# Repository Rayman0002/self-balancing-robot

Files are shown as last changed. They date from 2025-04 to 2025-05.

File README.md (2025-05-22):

# 🤖 Self-Balancing Robot - StabilOHM

## Inhaltsverzeichnis
- [Projektbeschreibung](#projektbeschreibung)
- [Bilder und Videos](#bilder-und-videos)
- [Komponenten](#komponenten)
- [Schaltskizze](#schaltskizze)
- [Libraries](#libraries)
- [Durchgeführte Arbeiten](#durchgeführte-arbeiten)
- [Herausforderungen und Probleme](#herausforderungen-und-probleme)
- [Mögliche Erweiterungen](#mögliche-erweiterungen)
- [Fazit](#fazit)

---

## Projektbeschreibung  

Das Ziel dieses Projekts war es, einen selbstbalancierenden zweirädrigen Roboter als Differentialantrieb zu entwerfen, zu fertigen und zu programmieren. Dabei handelt es sich um ein mechatronisches System, das aufrecht bleibt, indem es kontinuierlich den Neigungswinkel misst und entsprechend gegensteuert – vergleichbar mit einem inversen Pendel.

### Motivation
Selbstbalancierende Roboter sind ein beliebtes Thema in der Robotik, da sie komplexe Regelungstechnik mit Sensorik, Echtzeitverarbeitung und Aktorik verbinden. Dieses Projekt diente dem praktischen Verständnis dieser Disziplinen und der Integration moderner Komponenten wie ODrive-Motorsteuerungen, MPU6050-Sensorik und Echtzeitregelung mit einem Teensy 4.0 Microcontroller.

### Anforderungen
- Modularer Aufbau um Erweiterungen leicht zu ermöglichen
- 10 kg Tragfähigkeit
- 2 m/s Geschwindigkeit
- Höhe ca. 75 cm (Tischhöhe)
- mindestens 2 Stunden Betriebszeit
- Ansteuerbarkeit über ROS2
- Budget von 1000 €
- Veröffentlichung und Dokumentation via Github

Folgende Bauteile wurden hierfür gestellt:
- Zwei Servomotoren, gesteuert über je ein ODrive S1 Board
- Zwei Bleisäureakkumulatoren

### Technische Umsetzung
Um die gegebenen Anforderungen zu erfüllen wurden [folgende Bauteile](https://github.com/Rayman0002/self-balancing-robot/tree/01634058a8744456b4b8e9eb85bf182ba5505895/Bestellliste) zugekauft:
- Eine MPU6050 (IMU) zur Winkelmessung, welche über I2C ausgelesen wird
- Ein Teensy 4.0 (TCU) als Hauptcontroller für das Regelungssystem (PID) der Traktion
- Ein Raspberry Pi 5 (VCU) für höhere Funktionen wie Netzwerkzugang oder ROS2-Integration
- DC/DC Wandler
- Not-Aus-Schalter

Das Chassis wurde aus Aluminiumprofilen gefertigt, um Robustheit und Modularität zu gewährleisten. Zusätzlich wurden alle spezifischen Halterungen und Aufnahmen im 3D-Druckverfahren gefertigt.

### Steuerung und Regelung
Ein geschlossener Regelkreis sorgt dafür, dass der Roboter sein Gleichgewicht selbstständig hält: Die IMU MPU6050 misst fortlaufend den aktuellen Neigungswinkel (Ist-Wert) und speichert die Messwerte in einem FIFO-Buffer, aus dem anschließend ein gleitender Mittelwert gebildet wird. Dadurch werden Störungen und Rauschen in den Sensordaten reduziert. Der so geglättete Winkelwert wird mit dem gewünschten Sollwert verglichen. Aus der dabei entstehenden Abweichung berechnet ein PID-Regler eine passende Stellgröße. Diese wird für die Drehzahlsteuerung der Motoren verwendet, wodurch die Antriebsmotoren die Neigung aktiv ausgleichen und den Roboter in aufrechter Position halten.

---

## Bilder und Videos
Sämtliche Bilder sind ebenso noch separat im Ordner [Images](https://github.com/Rayman0002/self-balancing-robot/tree/b4acf35143aba7584a2bec3d086b7ce9a561bfc9/Images) einsehbar und downloadbar.

### Bild des Roboters
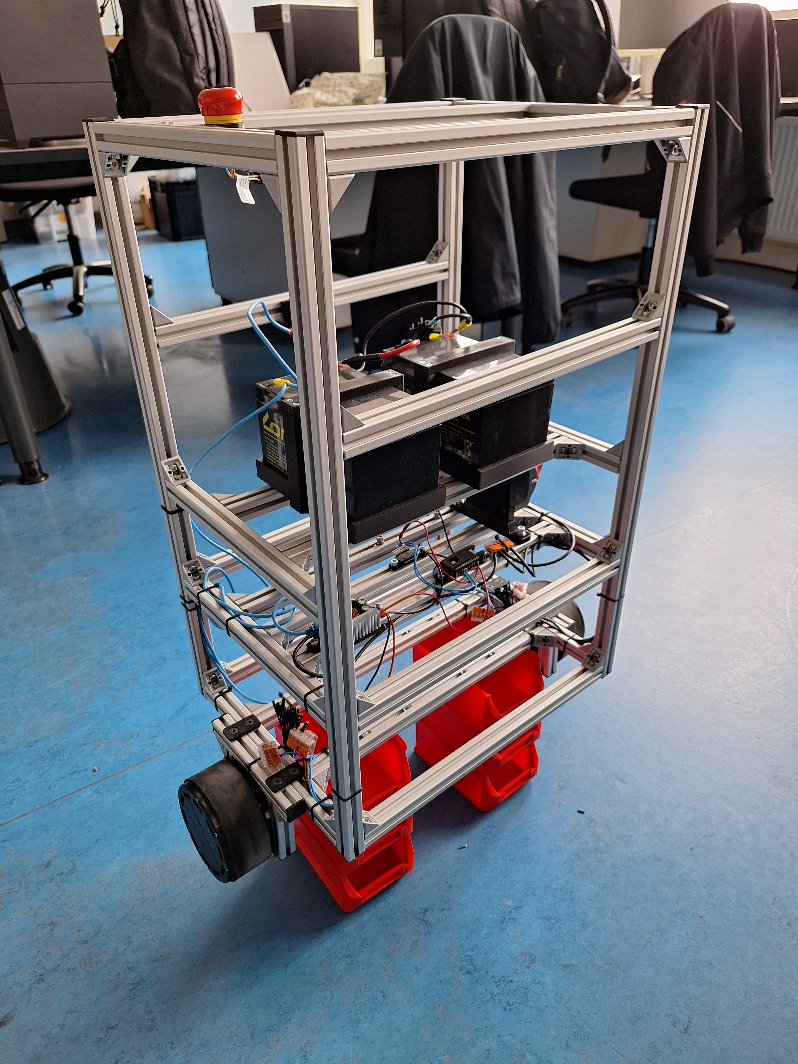
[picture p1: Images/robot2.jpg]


### Video des Balanciervorgangs
<a href="https://youtube.com/shorts/ZV-jEct9rSY">
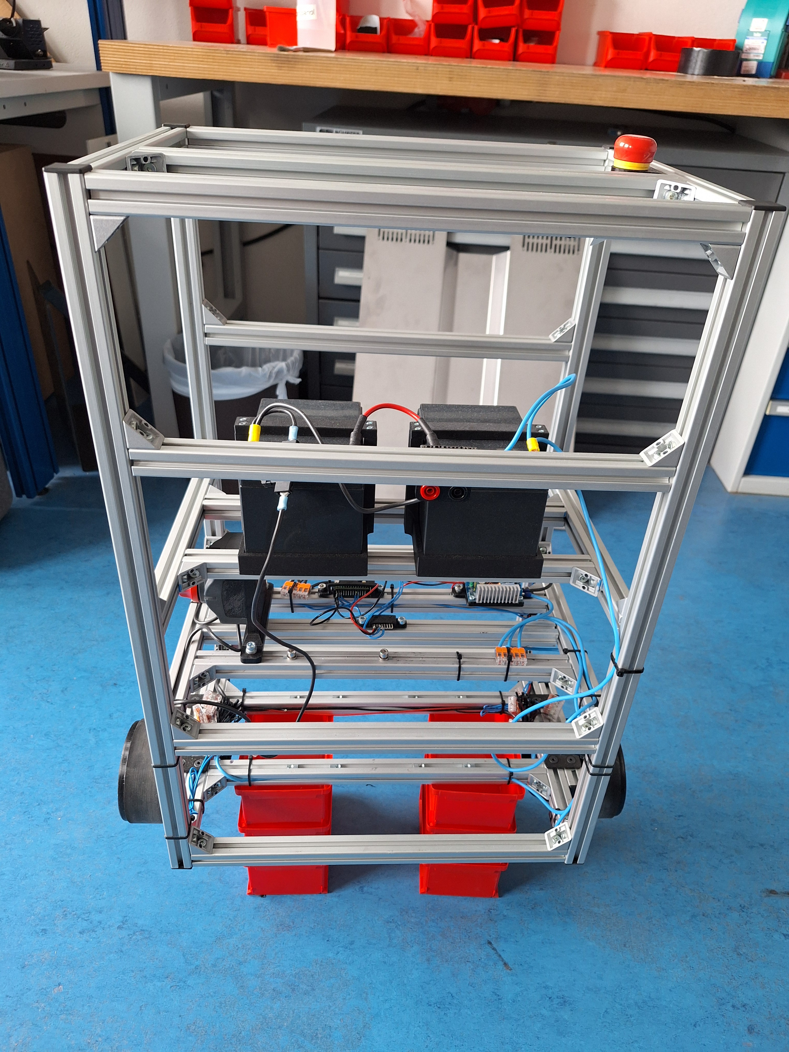
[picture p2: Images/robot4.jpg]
Balancierroboter
</a>

---

## Komponenten  
Hier ein Überblick über die wichtigsten Bauteile des Roboters:

- **Teensy 4.0 (TCU)**  
  Dient als Hauptcontroller des Roboters. Mit seiner hohen Taktrate (600 MHz) ist er ideal für rechenintensive Aufgaben wie die PID-Regelung und die Verarbeitung der Sensordaten in Echtzeit.

- **MPU6050 (IMU)**  
  Dieses Modul ist günstig und weit verbreitet, es enthält ein 3-Achsen-Gyroskop und einen 3-Achsen-Beschleunigungssensor. Es liefert kontinuierlich Informationen über die Lage und Bewegung des Roboters und ist damit die zentrale Sensoreinheit.

- **Raspberry Pi 5 (VCU)**  
  Er ermöglicht höhere Rechenleistung für zukünftige Erweiterungen wie ROS2-Anbindung, Fernsteuerung oder autonome Navigation.

- **ODrive S1 Board**  
  Eine hochentwickelte Motorsteuerung für die verwendeten Gleichstrommotoren. Sie erlaubt präzise Regelung der Motorbewegung und Kommunikation über UART.

- **ODrive M8325s Motoren**  
  Diese Motoren liefern das nötige Drehmoment und die Geschwindigkeit, um den Roboter zu bewegen und gleichzeitig das Gleichgewicht zu halten.

- **Blei-Akkumulator LB12-12**  
  Ein robuster und zuverlässiger 12 V Bleiakku mit hoher Kapazität (12 Ah), der eine Laufzeit von über 2 Stunden ermöglicht und gleichzeitig als Gegengewicht im Chassis dient.

---

## Schaltskizze  

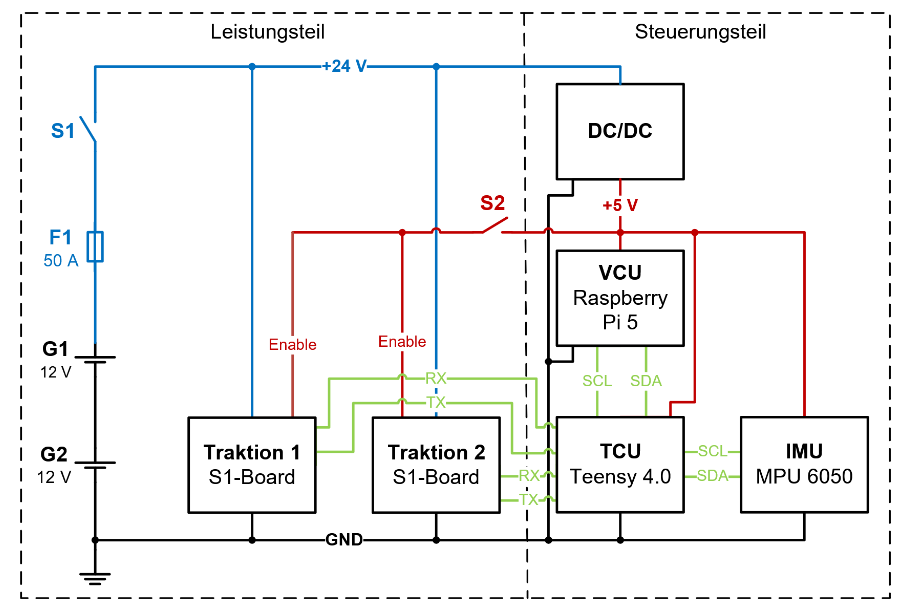
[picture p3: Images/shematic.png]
Schaltskizze


---

## Libraries  
Für die Realisierung der Softwarearchitektur kamen verschiedene spezialisierte Arduino- und C/C++-Bibliotheken zum Einsatz. Sie übernehmen wichtige Aufgaben wie die Kommunikation mit Sensoren, die Motorsteuerung und die Umsetzung der Regelalgorithmen:

- **Wire**  
  Die Standard-I2C-Bibliothek von Arduino, die für die Kommunikation mit dem MPU6050 verwendet wird. Sie ermöglicht den seriellen Datenaustausch zwischen dem Microcontroller und externen I2C-Geräten.

- **I2Cdev**  
  Eine benutzerfreundliche Schnittstellenbibliothek, entwickelt von Jeff Rowberg. Sie erleichtert das Auslesen von I2C-Sensoren wie dem MPU6050, indem sie die I2C-Kommunikation kapselt und abstrahiert.

- **MPU6050_6Axis_MotionApps20**  
  Ebenfalls von Jeff Rowberg, diese Erweiterung nutzt die „DMP“ (Digital Motion Processor)-Funktionalität des MPU6050, um bereits vorverarbeitete Lagedaten (Yaw, Pitch, Roll) bereitzustellen. Dies entlastet den Mikrocontroller und erhöht die Genauigkeit der Bewegungsanalyse.

- **PID_v1**  
  Eine bekannte PID-Regler-Bibliothek, die es ermöglicht, stabile Regelkreise zu entwickeln. Sie verarbeitet die Sensordaten in Echtzeit und berechnet das erforderliche Stellmoment für die Motoren, um das Gleichgewicht des Roboters zu halten.

- **ODriveUART**  
  Eine Bibliothek zur seriellen Kommunikation mit dem ODrive S1 Board über UART. Sie bietet eine einfache Schnittstelle zur Steuerung der Motoren, zum Auslesen von Statuswerten und zum Handling von Fehlerzuständen.

---

## Durchgeführte Arbeiten
Im Rahmen des Projekts wurden mehrere komplexe Teilaufgaben erfolgreich umgesetzt – sowohl im mechanischen als auch im softwareseitigen Bereich:

- **Mechanische Konstruktion**  
  Der Rahmen des Roboters besteht aus stabilen Aluminiumprofilen, die nicht nur für eine solide Bauweise sorgen, sondern auch viel Spielraum für Anpassungen bieten. Diese modulare Struktur macht es einfach, Bauteile flexibel zu montieren und bei Bedarf umzubauen.
  Alle mechanischen Teile – von den Halterungen über die Elektronikaufnahmen bis hin zu den Rädern selbst – wurden eigenständig konstruiert und mittels 3D-Druck gefertigt. Dadurch konnte jedes Teil passgenau auf die Anforderungen abgestimmt werden.
  Die Räder sind eine vollständige Eigenkonstruktion. Zum einen aus kostentechnischen Gründen, zum anderen um die Verbindung zwischen Motoren und Rädern möglichst einfach zu gestalten. Hierdurch erspart man sich die Verwendung eines Getriebes.
Auf das 3D-gedruckte Rad wurde mit einem doppelseitigem Klebeband ein Gummistreifen aufgeklebt, welcher aufgrund des hohen Grips dem Schlupf der Räder entgegenwirkt. Des Weiteren wurde ein dünnes Netz integriert, um zu verhindern, dass auf dem Boden liegende Schrauben oder andere Kleinteile in den Motor gelangen.
  Zudem wurde ein digitaler Zwilling in CAD entworfen, um einen modellbasierten Regelungsentwurf zu ermöglichen.

- **Sensorintegration & Kalibrierung**  
  Anbindung und Kalibrierung des MPU6050-Sensors über I2C mittels des Teensy 4.0.
  Ein Temperaturdrift ist feststellbar, spielt bei den vorhandenen Temperaturänderungen im herkömlichen Betrieb jedoch keine Relevanz. Mit der Nutzung eines Heißluftföhns kann der Drift nachgewiesen werden.
  Dadurch, dass die IMU im aufrecht stehenden Zustand des Roboters keinen Winkel von exakt 0° liefert, ist eine Offsetkorrektur notwendig. Dieser Offset kann empirisch ermittelt werden.   

- **Regelung & Antrieb**  
  Nutzung eines PID-Reglers, der in Echtzeit auf Winkelabweichungen reagiert und die Motoren gezielt ansteuert, um den Roboter auszubalancieren. Dabei wurden verschiedene PID Regelparameter ausgetestet, um ein möglichst stabiles Systemverhalten zu realisieren. Die aktuellen Regelparameter sind so gewählt, dass sie einen ausgewogenen Kompromiss bilden. Einerseits sind die Werte groß genug, um schnell auf Abweichungen vom Sollwert zu reagieren. Andererseits sind sie klein genug, um ein aufschwingendes Verhalten zu vermeiden und einen stabilen, sicheren Zustand zu gewährleisten.

- **Motorsteuerung mit ODrive**  
  Konfiguration und serielle Ansteuerung des ODrive-Boards zur präzisen Steuerung beider Radmotoren.

- **Softwareentwicklung**  
  Modularer, effizienter [C-Code](https://github.com/Rayman0002/self-balancing-robot/tree/3e0792b9f9f8d5dc3f43347506e3ac82a5c26bf6/Code) für den Teensy-Microcontroller.

---

## Herausforderungen und Probleme  
Während der Entwicklung traten verschiedene kritische Systemzustände auf, die das Verhalten des Roboters massiv beeinflussten. Einige dieser „Sackgassen“ führten dazu, dass das System einen instabilen Zustand oder ein unzufriedenstellendes Ergebnis aufwies. 
Die zentralen Ursachen waren:

- **Maximale Drehzahl**  
  In der Motorkonfiguration kann die maximale Drehzahl der Motoren begrenzt werden. Dies entspricht einer Stellsignalbegrenzung, was zu einem instabilen Systemverhalten führt. 

- **Komplementärfilter als Fehlerquelle**  
  In einem früheren Entwicklungsstadium wurde ein Komplementärfilter zur Sensorfusion eingesetzt, um die Neigungsdaten aus Gyroskop und Beschleunigungssensor zu kombinieren. Leider führte dieser Filter – vermutlich durch falsche Parameter oder ungünstige Gewichtung (wobei sehr viele Parameter getestet wurden) – zu einer ungenauen oder verzögerten Winkelberechnung. Das Resultat war, dass der Roboter nicht balancierte oder sogar instabil reagierte. Erst nach Entfernung des Filters und direkter Nutzung der DMP-Daten des MPU6050 konnte das System zuverlässig auf Winkeländerungen reagieren.

- **Höhere Reglerzykluszeit**  
  Eine stabile Regelung des Roboters setzt eine konstante und ausreichend schnelle Regelzykluszeit voraus.
  Eine zu große Reglerzykluszeit hatte zur Folge, dass der Sollwert zu selten abgetastet wird und somit zu langsam auf eine Winkeländerung reagiert werden kann.
  In einem früheren Softwarestand wurde zyklisch der Zustand der Motoren überprüft und ein gegebenenfalls vorhandener Fehler quittiert. Dies führte dazu, dass die Reglerzykluszeit erhöht wurde.
  Bei einer zu geringen Reglerzykluszeit hat das System auch instabil reagiert. Hierbei konnte die Fehlerursache jedoch nicht ausfindig gemacht werden.
  Eine Zykluszeit von 5 ms hat sich als passend herausgestellt.

- **ODrive-Dokumentation**  
  Die offizielle Dokumentation war teilweise lückenhaft, widersprüchlich oder unvollständig, was den Einstieg deutlich erschwerte. Vieles musste durch Eigenversuche oder Community-Beiträge erarbeitet werden.

---

## Mögliche Erweiterungen
Im weiteren Projektverlauf bieten sich zahlreiche sinnvolle Erweiterungsmöglichkeiten, um die Funktionalität, Sicherheit und Autonomie des Roboters zu verbessern. Im Folgenden werden zwei Projektarbeiten formuliert mit entsprechenden Aufgabenpaketen:

### Projektarbeit 1 – Softwareseitige Erweiterung des Robotersystems durch Integration von micro-ROS und fortgeschrittener Regelung

- **Einbindung von micro-ROS**  
  Durch die Anbindung des Systems an ROS2 mittels micro-ROS kann der Roboter in ein größeres Robotik-Ökosystem integriert werden. Hierfür muss der vorhandene Code des Teensy's in einen micro-ROS Rahmen integriert werden. Dies ermöglicht z. B. eine dynamische Regelparameteranpassung, Logging der Messwerte und Fernsteuerung des Roboters. 

- **Fernsteuerung**  
  Die Fernsteuerung erfolgt über ROS2, wobei ein Controller per Bluetooth oder USB mit dem Laptop verbunden ist. Dieser kommuniziert wiederum über WLAN mit dem auf dem Roboter verbauten Raspberry Pi.

- **Erweiterte Regelungsalgorithmen**  
  Anstelle des klassischen PID-Reglers könnte ein modellbasierter Zustandsregler eingesetzt werden. Solche Methoden erlauben eine präzisere Reaktion auf komplexe Dynamiken, insbesondere bei wechselnder Last oder höherer Geschwindigkeit. Denkbare Zustände wären die Geschwindigkeit, Position des Roboters ausgelesen über die Motoren sowie der Winkel und die Winkeländerungsrate ausgelesen über die IMU. Des Weiteren kann eine Kaskadenregelung umgesetzt werden, sodass eine bessere Positionstreue, insbesondere im beladenen Zustand, erzielt wird.

- **Autonome Navigation & Kartographierung (SLAM)**  
  Eine langfristige Erweiterung ist die Ausstattung mit LiDAR oder Kamera zur Umgebungswahrnehmung. Mittels SLAM (Simultaneous Localization and Mapping) könnte der Roboter eigenständig Räume kartieren und navigieren.

### Projektarbeit 2 - Mechanische Optimierung und Erweiterung des Roboters durch Not-Aus-Schalter und zusätzlichen Roboterarm

- **Integration eines Not-Aus-Schalters**  
  Für den sicheren Betrieb ist ein physischer Not-Aus-Schalter essenziell. Dieser soll die Stromzufuhr zu den Motoren sofort unterbrechen und im Fehlerfall Schäden oder Verletzungen verhindern. Der Not-Aus-Schalter muss hierzu über die Enable-Pins des S1-Boards angeschlossen werden. Das notwendige Vorgehen ist in der [ODrive Dokumentation](https://docs.odriverobotics.com/v/latest/manual/error-enable.html) beschrieben.

- **Batteriespannungsüberwachung**  
  Für den sicheren Betrieb des Roboters ist es sinnvoll die Spannungen der Batterien zu überwachen, um so eine Tiefentladung der Batterien zu verhindern. Der sichere Betrieb ist somit gewährleistet, da die Motoren in keinen Fehlerzustand wegen Unterspannung gelangen.

- **Mechanische Verkleidung**  
  Um die empfindlichen elektronischen Komponenten vor äußeren Einflüssen wie Staub, Feuchtigkeit oder mechanischen Stößen zu schützen, soll eine robuste Außenverkleidung entworfen werden. Sie soll außerdem unabsichtliches Anfassen der Komponenten verhindern. Diese sollte wartungsfreundlich umgesetzt sein. Gleichzeitig dient sie der strukturellen Verstärkung des Chassis. Darüber hinaus ist ein Bereich für einen Materialtransport vorzusehen.

- **passive Sicherheitsmaßnahmen**  
  Zur Absicherung bei einem Ausfall der Regelung oder anderer kritischer Fehlerzustände wird ein mechanischer Umfallschutz implementiert. Dieser wirkt als passive Auffangsicherung, die im Ernstfall ein vollständiges Umkippen des Roboters verhindert. Hierdurch sollen außerdem Beschädigungen durch das Umfallen verhindert werden. Denkbare Lösungen sind seitlich oder hinten montierte Stützrollen oder eine dämpfende Fangstruktur (z. B. mit Federn oder Gummipuffern), die bei zu großer Neigung des Roboters den Kontakt zum Boden aufnehmen und ein kontrolliertes Abfangen ermöglichen. Wichtig ist dabei, dass die Konstruktion die normale Bewegung des Roboters nicht einschränkt und möglichst leicht und robust gestaltet ist.

---

## Fazit
Das Projekt hat gezeigt, dass sich ein selbstbalancierender Zweirad-Roboter mit Hilfe einer MPU6050-IMU, eines PID-Reglers und ODrive-Motorsteuerungen zuverlässig stabilisieren lässt. Zu Beginn verzögerte ein suboptimaler Ansatz mit einem Komplementärfilter die Stabilisierung erheblich und auch das Auffinden geeigneter PID-Parameter sowie die exakte Bestimmung des Sollwerts erwiesen sich als große Herausforderung. Erst nach intensiver Feinabstimmung der Reglerzykluszeit und Anpassung der Regelparameter konnte der Roboter dauerhaft balancieren. Innerhalb des vorgegebenen Budgets und mit modularem Aufbau wurden nahezu alle Anforderungen – von der Tragfähigkeit über die Fahrgeschwindigkeit bis zur Akkulaufzeit – erfüllt. Künftige Erweiterungen wie micro-ROS-Integration, autonome Navigation und erweiterte Regelungsalgorithmen bieten viel Potenzial, um den Roboter noch vielseitiger und robuster zu machen.

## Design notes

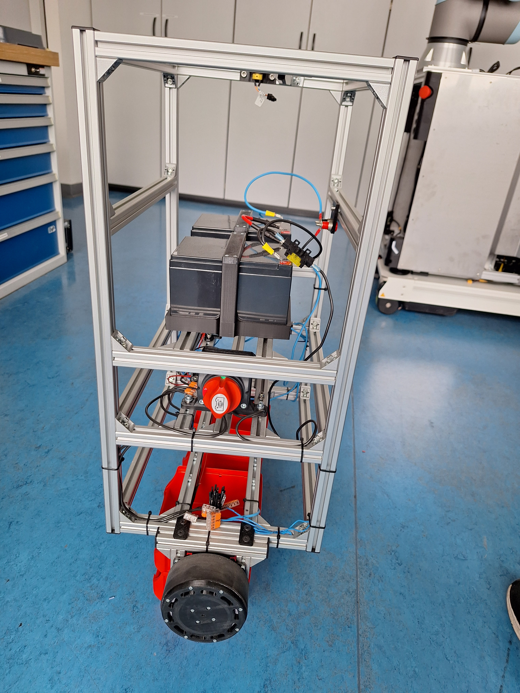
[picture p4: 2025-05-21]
Images/robot6.jpg

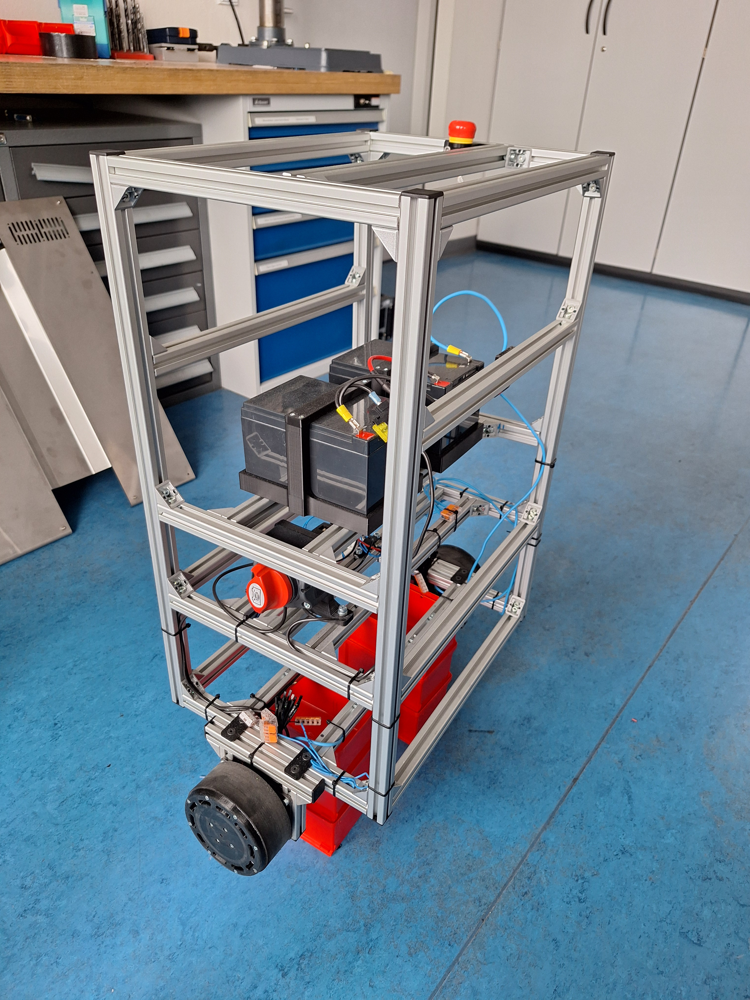
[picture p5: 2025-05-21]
Images/robot5.jpg

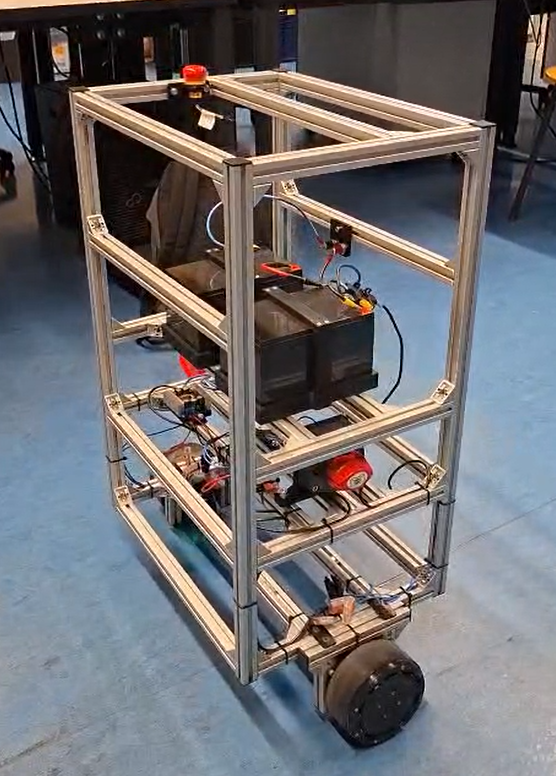
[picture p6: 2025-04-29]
Images/roboter.png

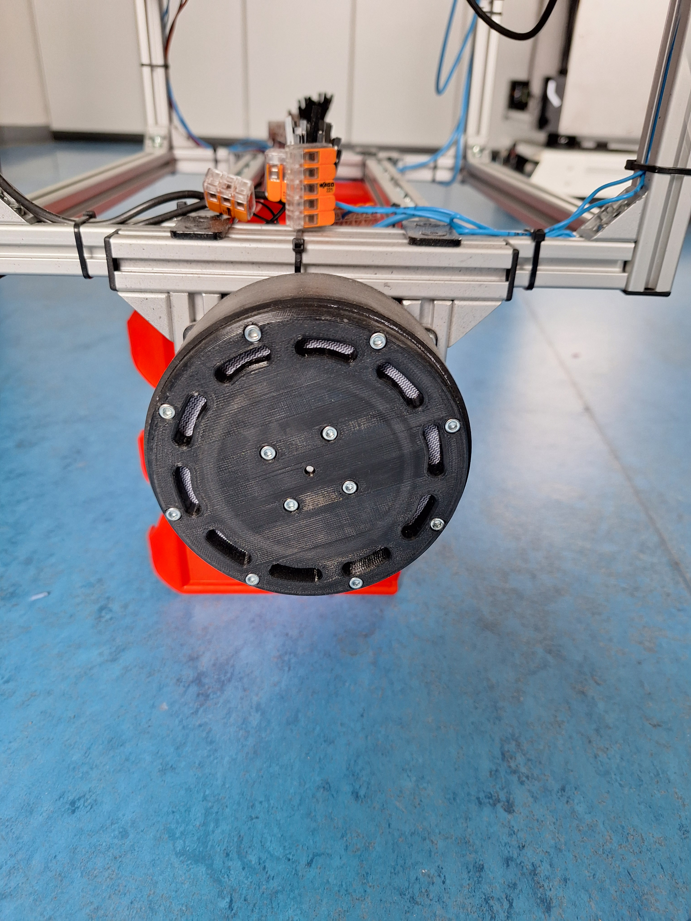
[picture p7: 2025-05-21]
Images/robot7.jpg

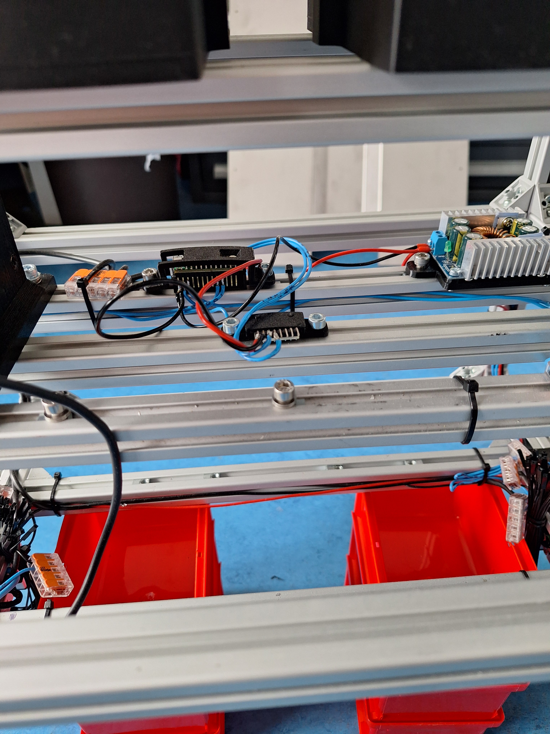
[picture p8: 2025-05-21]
Images/robot1.jpg

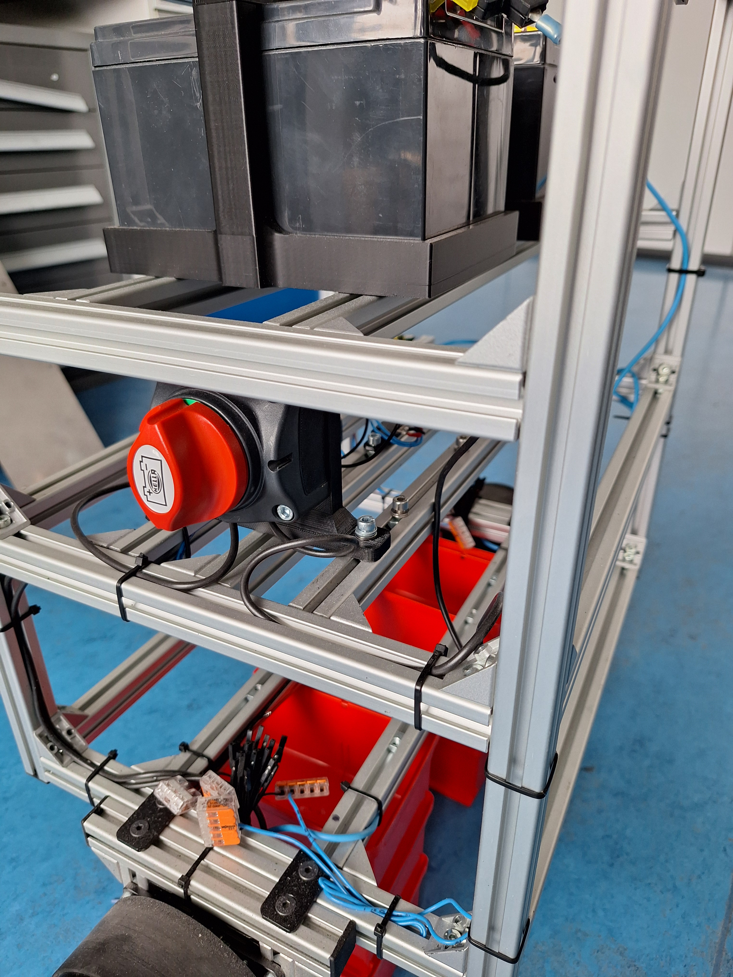
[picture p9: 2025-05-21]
Images/robot8.jpg

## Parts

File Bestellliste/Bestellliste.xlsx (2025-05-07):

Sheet: Bestellung 1
Beschreibung | Link | Status | Packungseinheit | Anzahl | Stückpreis | Betrag | Erhalten
Teensy 4.0 | https://www.reichelt.de/teensy-4-0-usb-ohne-header-teensy-4-0-p269006.html?&trstct=vrt_pdn&nbc=1 | bestellt | 1 | 1 | 29.50 € | 29.50 € | x
Raspberry pi 5 | https://www.reichelt.de/de/de/raspberry-pi-5-b-4x-2-4-ghz-4-gb-ram-wlan-bt-rasp-pi-5-b-4gb-p359842.html?r=1 | bestellt | 1 | 1 | 65.50 € | 65.50 € | x
Winkel, Schrauben, Nutensteine | https://tktrading24.de/Befestigungswinkel-ink-Schrauben-und-Nutensteine-Nut-6-fuer-Aluprofil-20-er-10-Stueck | bestellt | 10 | 5 | 10.92 € | 54.60 € | x
Nutensteine mit Feder | https://tktrading24.de/Nutenstein-mit-Federkugel-und-Steg-M5-Nut-6-fuer-Aluprofil-20-er-10-Stueck | bestellt | 10 | 5 | 4.70 € | 23.50 € | x
Kabel | https://www.reichelt.de/schaltlitze-h07v-k-2-5-mm-10-m-blau-h07vk-2-5-10bl-p69520.html?trstct=pol_0&nbc=1 | bestellt | 10 | 1 | 6.75 € | 6.75 € | x
Kabel | https://www.reichelt.de/schaltlitze-h07v-k-2-5-mm-10-m-schwarz-h07vk-2-5-10sw-p69519.html?trstct=pol_2&nbc=1 | bestellt | 10 | 1 | 7.20 € | 7.20 € | x
Kabel | https://www.reichelt.de/kfz-fahrzeugleitung-flry-1-5mm-5m-rot-flk-1-5-rt-5-p31780.html?trstct=vrt_pdn&nbc=1 | bestellt | 5 | 1 | 3.99 € | 3.99 € | x
Kabel | https://www.reichelt.de/kfz-fahrzeugleitung-flry-1-5mm-5m-schwarz-flk-1-5-sw-5-p31774.html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 | bestellt | 5 | 1 | 3.99 € | 3.99 € | x
Kabel | https://www.conrad.de/de/p/quadrios-23cw025-einzelader-0-5-mm-schwarz-25-m-2870619.html | bestellt | 25 | 1 | 9.99 € | 9.99 € | x
Kabel | https://www.conrad.de/de/p/quadrios-23cw024-einzelader-0-5-mm-rot-25-m-2870617.html | bestellt | 25 | 1 | 9.99 € | 9.99 € | x
Aderendhülsen Set | https://www.conrad.de/de/p/quadrios-22c482-aderendhuelsen-sortiment-0-5-mm-0-75-mm-1-mm-2-5-mm-teilisoliert-400-st-2870586.html | bestellt | 400 | 1 | 5.99 € | 5.99 € | x
Klebesockel | https://www.conrad.de/de/p/tru-components-tc-hc19r203-befestigungssockel-selbstklebend-1593034-buendel-o-bereich-3-mm-max-4fach-einfaedeln-transpa-1593034.html | bestellt | 25 | 1 | 4.50 € | 4.50 € | x
Heat inserts | https://www.reichelt.de/3d-druck-gewindeeinsaetze-m3x5-7-100-stueck-rx-m3x5-7-p332213.html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 | bestellt | 1 | 1 | 8.99 | 8.99 € | x
Heat Insert Werkzeug | https://www.reichelt.de/3d-druck-loetspitzen-einschmelzhilfe-set-8-stueck-rx-loe-set-011-p360680.html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 | bestellt | 1 | 1 | 16.99 € | 16.99 € | x
M5 Schrauben | https://www.conrad.de/de/p/conrad-839597-innensechskantschrauben-m5-16-mm-innensechskant-stahl-verzinkt-100-st-839597.html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 | bestellt | 100 | 1 | 10.99 € | 10.99 € | x
Beschleunigung & Gyroskop Sensor | https://www.reichelt.de/entwicklerboards-beschleunigung-gyroskop-mit-header-mpu-60-debo-sens-3axish-p266105.html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 | bestellt | 1 | 1 | 3.80 € | 3.80 € | x
Luftfilter für Räder | https://www.caseking.de/akasa-fan-grille/LUAK-050.html | bestellt | 1 | 2 | 4.90 € | 9.80 € | x
Aluprofil-Verbindungsplatte | https://www.alu-profil-technik.de/Verbindungsplatte-20-x-40-schwarz-mit-Befestigung-fuer-Aluprofil-20-Nut-6-B.html | bestellt | 1 | 8 | 2.95 € | 23.60 € | x
 |  |  |  |  | Summe: | 299.67 €

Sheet: Bestellung 2
Beschreibung | Link | Status | Packungseinheit | Anzahl | Stückpreis | Betrag | Erhalten
Acryplatten | https://kunststoffplattenonline.de/product/acrylglas-xt-platten-transparent-klar-3-mm/
2K-Kleber | https://de.rs-online.com/web/p/klebstoff/0850940?gb=s |  | 2 | 1 | 13.84 € | 13.84 € | anderen
 |  |  |  |  |  | 0.00 €
Flachstecker |  |  |  |  |  | 0.00 €
Male-Male Jumperkabel |  |  |  |  |  | 0.00 €
Stiftleisten |  |  |  |  |  | 0.00 €
Kabelbaum S1 Board |  |  |  |  |  | 0.00 €
PETG Filament | https://www.prusa3d.com/de/produkt/prusament-petg-jet-black-1kg/ |  | 1 | 1 | 29.99 € | 29.99 €
 |  |  |  |  | Summe: | 43.83 €

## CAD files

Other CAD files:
CAD/wheel-assembly.step
CAD/main-switch-bracket.step
CAD/battery-bracket.step
CAD/teensy-bracket.step
CAD/dcdc-bracket.step
CAD/imu-mpu6050-bracket.step
CAD/emb-bracket.step
CAD/robot-digital-twin.step

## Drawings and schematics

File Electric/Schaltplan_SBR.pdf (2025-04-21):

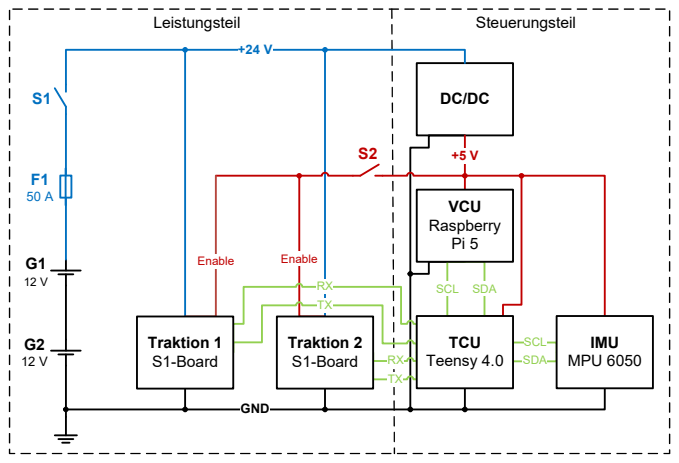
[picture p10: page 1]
GND; Enable; SCL SDA; SDA; SCL; IMU; MPU 6050; VCU Raspberry Pi 5; Traktion 2 S1-Board; TCU Teensy 4.0; Traktion 1 S1-Board; Leistungsteil; Steuerungsteil

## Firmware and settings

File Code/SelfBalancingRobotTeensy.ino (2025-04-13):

#include <Wire.h>
#include "I2Cdev.h"
#include <ODriveUART.h>
#include <PID_v1.h>
#include "MPU6050_6Axis_MotionApps20.h"

// Anlegen der UART-Schnittstellen zu OdriveMotoren
HardwareSerial& odriveSerial1 = Serial1; // Serial1 für ersten Motor
HardwareSerial& odriveSerial2 = Serial2; // Serial2 für zweiten Motor
ODriveUART odriveM1(odriveSerial1);
ODriveUART odriveM2(odriveSerial2);

// MPU Variablen
MPU6050 mpu;
bool dmpReady = false;  
byte mpuIntStatus, devStatus;   
unsigned int packetSize;        
unsigned int fifoCount;     
byte fifoBuffer[64]; 

// Winkelberechnung
Quaternion q;           // rotation and acceleration data 
VectorFloat gravity;    // gravity data of MPU
float ypr[3];           // yaw, pitch and roll data

// PID Variablen
double setpoint = 4.38;  // Sollwinkel: Trotz Kalibirierung bleibt ein Offset von ca. 4° erhalten
double PIDin, PIDout;
double Kp = 2.2; //2.2
double Ki = 4.2; //4.2
double Kd = 0.04; //0.04

// Anlegen der PID-Instanz
PID pid(&PIDin, &PIDout, &setpoint, Kp, Ki, Kd, DIRECT);

volatile bool mpuInterrupt = false;     
void dmpDataReady(){  
  mpuInterrupt = true;
}

void setup() {
    Serial.begin(250000);
    Wire.begin();
    mpu.initialize();
    devStatus = mpu.dmpInitialize();
    
    // Ermittelte Offsetwerte durch Kalibriermessung
    mpu.setXGyroOffset(100);
    mpu.setYGyroOffset(119);
    mpu.setZGyroOffset(92);
    mpu.setZAccelOffset(1644);

    // MPU Setup
    if (devStatus == 0) {
        Serial.println(F("MPU starting"));
        mpu.setDMPEnabled(true);
        attachInterrupt(0, dmpDataReady, RISING);
        mpuIntStatus = mpu.getIntStatus();
        Serial.println(F("MPU ready"));
        dmpReady = true;
        packetSize = mpu.dmpGetFIFOPacketSize();

        // PID Setup
        pid.SetMode(AUTOMATIC);
        pid.SetSampleTime(5);
        pid.SetOutputLimits(-255, 255);
    } else {
        Serial.print("DMP failed ");
        Serial.print(devStatus); 
    }
  	
    // Odrive Setup
    odriveSerial1.begin(115200);
    odriveSerial2.begin(115200);
    initializeOdrive(odriveM1);
    initializeOdrive(odriveM2);
    
}

void initializeOdrive(ODriveUART& odrive) {
    while (odrive.getState() == AXIS_STATE_UNDEFINED) {
        delay(100);
    }
    while (odrive.getState() != AXIS_STATE_CLOSED_LOOP_CONTROL) {
        odrive.clearErrors();
        odrive.setState(AXIS_STATE_CLOSED_LOOP_CONTROL);
        delay(10);
    }
}

void loop() {
    if (!dmpReady) return; // Fehlerabfrage falls MPU nicht richtig initialisiert wurde
    
    mpuInterrupt = false;
    mpuIntStatus = mpu.getIntStatus();
    fifoCount = mpu.getFIFOCount();

    if ((mpuIntStatus & 0x10) || fifoCount == 1024) {
        mpu.resetFIFO();
        Serial.println(F("FIFO overflow!"));
    } else if (mpuIntStatus & 0x02) {
        // MPU Buffer über dmp auslesen
        while (fifoCount < packetSize) fifoCount = mpu.getFIFOCount();
        mpu.getFIFOBytes(fifoBuffer, packetSize);
        fifoCount -= packetSize;
        mpu.dmpGetQuaternion(&q, fifoBuffer);
        mpu.dmpGetGravity(&gravity, &q);
        mpu.dmpGetYawPitchRoll(ypr, &q, &gravity);

        // Regler anwenden
        PIDin = ypr[1] * 180 / M_PI;
        pid.Compute();
        
        // Motoren ansteuern
        odriveM1.setVelocity(PIDout);
        odriveM2.setVelocity(-PIDout);
        
        /*
        // Debug-Ausgabe
        Serial.print("Neigung: ");
        Serial.print(ypr[1] * 180 / M_PI);
        Serial.print(" | PIDout: ");
        Serial.println(PIDout);
        */
    }
}

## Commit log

2025-04-09 Create test.md
    CAD Folder
2025-04-09 Create arduino folder
2025-04-14 Rename 230912_RASPBERRY_PI_5_PRODUCT_BRIEF_V2 2024-10-20 18_04_48.pdf to Raspberry_Pi_5
2025-04-14 Rename DEV-15583_ENG_TDS 2024-10-20 18_55_47.pdf to Teensy_4-0_pinout
2025-04-14 Rename rp1-peripherals 2024-10-20 18_11_48.pdf to Raspberry_Pi_peripherals.pdf
2025-05-07 Rename shematic.png to Circuit diagram.png
2025-05-10 Update README.md
    Abkürzungen, Servomotor
2025-05-22 Name und Projektarbeiten
